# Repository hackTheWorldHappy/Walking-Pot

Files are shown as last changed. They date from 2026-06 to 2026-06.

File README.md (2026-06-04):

# WaPo Walking-Pot



A Pot on 6 Legs that walks towards the sun, to achive the best for it's flower.

While doing the project, I learned a lot of new Stuff. Before beginning this Project, I never touched a PCB modeling software. I did 3d Modelling a few time, but the best i got was a dice. So this Project is a step up. The Things I learned while doing this project, will help me a lot with other Projects.

## Key Facts
WaPo has 6 Legs with 3 Servo motors each to navigate the world.
To know where to go WaPo uses 8 light sensors/resistors to check the light levels around him.
WaPo will find the sensor with the most light, then it will rotate/move in the direction where the most light is registered. 

The PCB has a ESP Wroom chip and 2 PCA9685 LED/Servo Drivers, to be able to controll all 18 Servos at once.
The PCB fits into the bottom of the Pot.

## Why WaPo?
Besides that my plants are not living the best life (weak lightning), I want to explore Hexapods and the combination of all these servos to acctually move the robot.
Maybe that's the only way my plants can survive :)
My Idea was, to set WaPo on the Ground power it on and see where it goes to find the best Spot.

## How to Build your Own WaPo?
You can build your own WaPo by following these instructions: [INSTRUCTIONS.md](https://github.com/hackTheWorldHappy/Walking-Pot/blob/main/INSTRUCTIONS.md)

## Visuals
**Assembled 3D model**

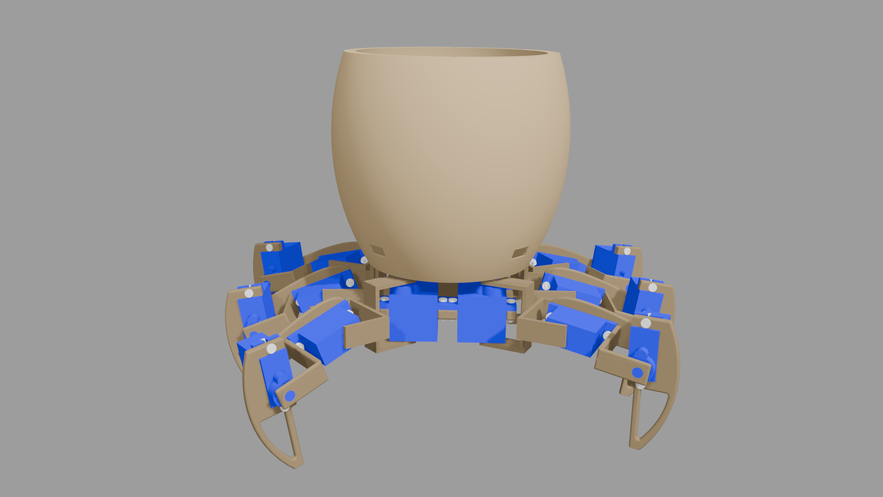
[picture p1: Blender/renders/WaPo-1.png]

<br>

**PCB 3D Model**

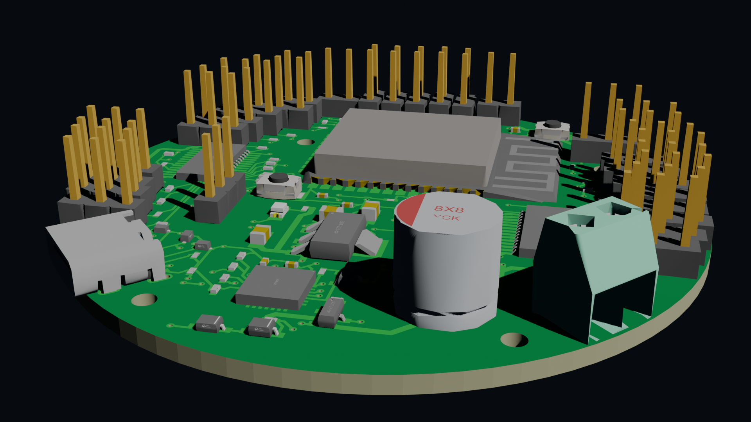
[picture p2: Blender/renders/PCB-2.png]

<br>

**PCB Schematic**

[WaPo-Schematic.pdf](https://github.com/hackTheWorldHappy/Walking-Pot/blob/main/SCH_WaPo-Schematic_2026-05-25.pdf)
<br>

**PCB Layout**

[PCB_wapo.pdf](https://github.com/hackTheWorldHappy/Walking-Pot/blob/main/PCB_PCB_wapo.pdf)

<br>

## Zine

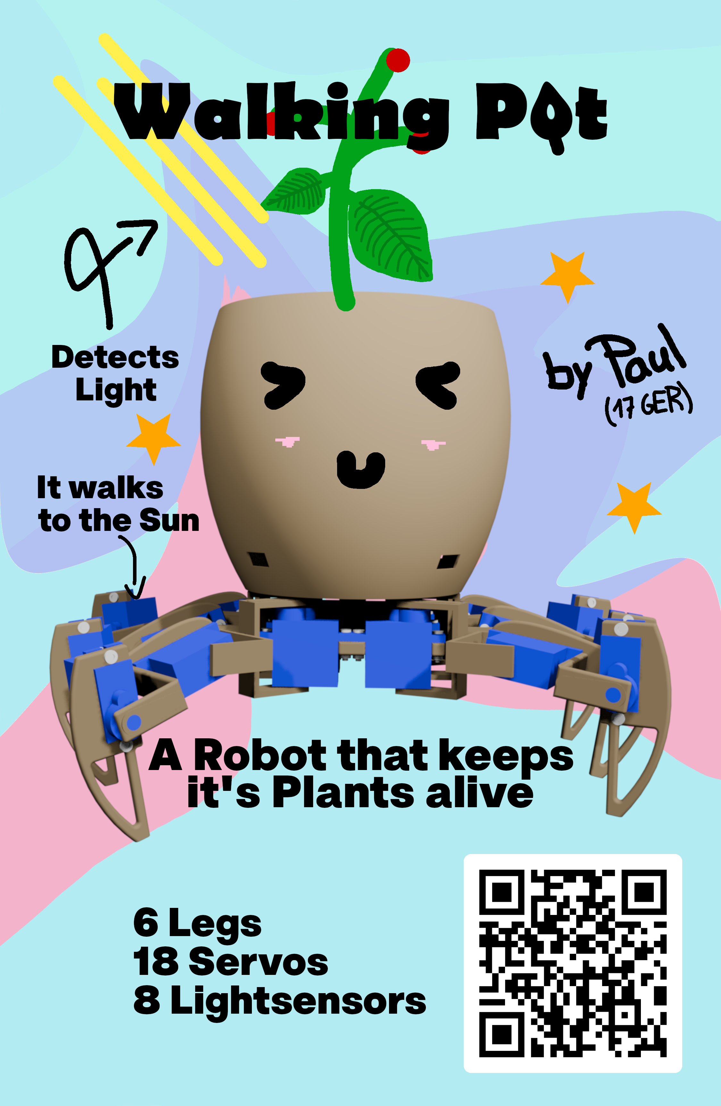
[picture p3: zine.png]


As a PDF: [Zine.pdf](https://github.com/hackTheWorldHappy/Walking-Pot/blob/main/zine.pdf)

---

## BOM
Name | Quantity | Price (for all) | Price in USD |Link
:------:|:-------:|:-------:|:-------:|:-------:
PCB (x5) | 1 (5) | ~22,73€ | ~26.44$ | [JLCPCB](https://jlcpcb.com) 
Servos sg90 | 18 | ~0,70€ | ~0.81$ | [AliExpress](https://de.aliexpress.com/item/1005007104370383.html)
Light Resistors | 8 | ~24,06€ | ~27.99$ | [AliExpress](https://de.aliexpress.com/item/32966282692.html)
M2 8mm Screws | 24 | ~0,79€ | ~0.92$ | [AliExpress](https://de.aliexpress.com/item/1005002247282771.html)
M2 10mm Screws | 12 | ~0,41€ | ~0.48$ | [AliExpress](https://de.aliexpress.com/item/1005002247282771.html)
M2 Nuts | 36 | ~1,13€ | ~1.31$ | [AliExpress](https://de.aliexpress.com/item/1005008314195033.html)  
Cables | 16 | ~2,11€ | ~2.45$ | [AliExpress](https://de.aliexpress.com/item/1005007046465880.html)
4.8V 3000mAh Battery | 1 | ~9,64€ | ~11.22$ | [AliExpress](https://de.aliexpress.com/item/1005006690430909.html)
PLA Filament Spool | 1 | ~15,43€ | ~17.95$ | [Amazon](https://www.amazon.com/dp/B0CD161SQR)
Total | | ~77,67€ | ~90.37$ | [BOM-all.csv](https://github.com/hackTheWorldHappy/Walking-Pot/blob/main/BOM-all.csv)
Actual Total* | | ~102,56€ | ~119.33$

*Actual Total: Cost including shipping and actual package size (Screws/Nuts come in 50PCS, Light resistors in 10)

View the PCB BOM as CSV: [BOM-PCB.csv](https://github.com/hackTheWorldHappy/Walking-Pot/blob/main/BOM-PCB.csv) <br>
View the BOM as CSV: [BOM.csv](https://github.com/hackTheWorldHappy/Walking-Pot/blob/main/BOM.csv)

---

## Firmware
### Libaries used in Firmware
https://github.com/adafruit/Adafruit-PWM-Servo-Driver-Library/tree/master

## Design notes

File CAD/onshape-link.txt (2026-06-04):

https://cad.onshape.com/documents/2002fa13ffcb19ab85ecd8a2/w/ecd96c98c772df3739a212b4/e/4dd37f64866b9c8d5d34c51d

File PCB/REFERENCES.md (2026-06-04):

# Refernces used for schematics/PCB creation:

### ESP32 WROOM Schematic
https://dl.espressif.com/dl/schematics/esp32_devkitc_v4_sch.pdf

### Adafruit PCA9685


_https://raw.githubusercontent.com/adafruit/Adafruit-16-Channel-PWM-Servo-Driver-PCB/refs/heads/master/Adafruit%20PCA9685.png_

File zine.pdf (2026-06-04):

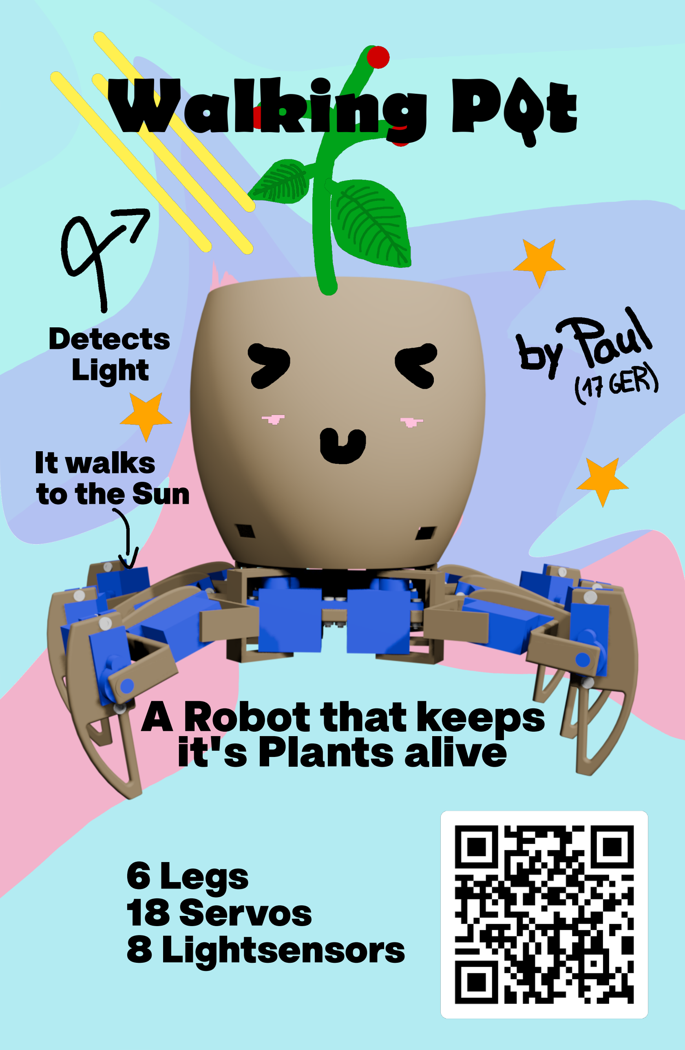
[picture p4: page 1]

### 6 Legs 18 Servos 8 Lightsensors

Light

Detects

to the Sun

It walks

A Robot that keeps it's Plants alive

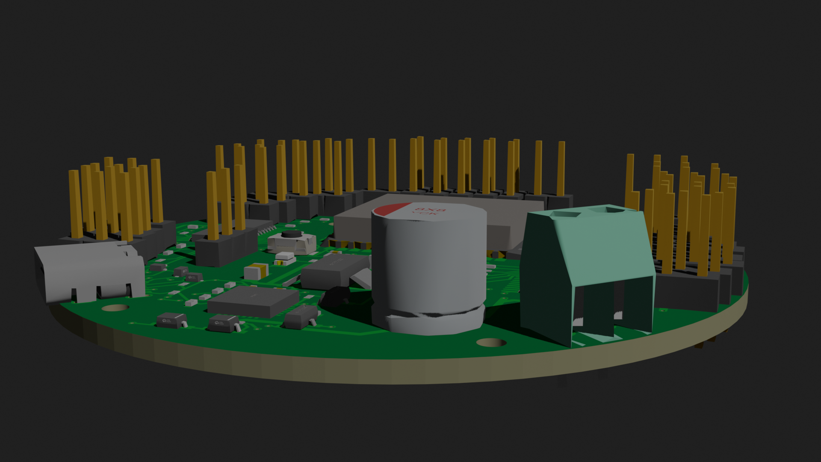
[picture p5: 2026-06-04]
Blender/renders/PCB-1.png

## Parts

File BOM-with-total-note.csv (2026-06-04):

No. | Quantity | Name | Comment | Designator | Footprint | Value | Manufacturer Part | Manufacturer | Supplier Part | Supplier | Price | Price * Quantity | per package Price | Link
1 | 3 | Capacitor | 22uF | C1,C3,C4 | C0805 | 22uF | CL21A226MPQNNNE | SAMSUNG(??) | C29277 | LCSC | 0,0038 € | 0,0114 € |  | https://www.lcsc.com/product-detail/C29277.html
2 | 5 | Capacitor | 100nF | C2,C5,C6,C7,C9 | C0402 | 100nF | CL05B104KO5NNNC | SAMSUNG(??) | C1525 | LCSC | 0,0003 € | 0,0015 € |  | https://www.lcsc.com/product-detail/C1525.html
3 | 1 | Capacitor | 10uF | C8 | C0402 | 10uF | CL05A106MP5NUNC | SAMSUNG(??) | C315248 | LCSC | 0,0015 € | 0,0015 € |  | https://www.lcsc.com/product-detail/C315248.html
4 | 2 | Capacitor | 10uF | C10,C11 | C0402 | 10uF | CL05A106MQ5NUNC | SAMSUNG(??) | C15525 | LCSC | 0,0011 € | 0,0022 € |  | https://www.lcsc.com/product-detail/C15525.html
5 | 1 | Capacitor | 1000uF | C12 | CAP-TH_BD8.0-P3.50-D0,6-FD | 1000uF | KM1A102MF115A00CV0 | HUAWEI(????) | C189254 | LCSC | 0,0091 € | 0,0091 € |  | https://www.lcsc.com/product-detail/C189254.html
6 | 1 | Diode | 1N4148WS | D1 | SOD-323_L1.8-W1.3-LS2.5-RD |  | 1N4148WS | CJ(????/??) | C2128 | LCSC | 0,0014 € | 0,0014 € |  | https://www.lcsc.com/product-detail/C2128.html
7 | 1 | Diode | BAT760-7 | D2 | SOD-323_L1.8-W1.3-LS2.5-RD |  | BAT760-7 | DIODES(??) | C124187 | LCSC | 0,0092 € | 0,0092 € |  | https://www.lcsc.com/product-detail/C124187.html
8 | 3 | TVS Diode | LESD5D5.0CT1G | D3,D4,D5 | SOD-523_L1.2-W0,8-LS1.6-BI |  | LESD5D5.0CT1G | UMW(?????) | C5199850 | LCSC | 0,0022 € | 0,0066 € |  | https://www.lcsc.com/product-detail/C5199850.html
9 | 8 | 2-Pin Male Header | PZ254V-11-02P | H1,H2,H3,H4,H5,H6,H7,H8 | HDR-TH_2P-P2.54-V-M |  | PZ254V-11-02P | XFCN(??) | C492401 | LCSC | 0,0024 € | 0,0192 € |  | https://www.lcsc.com/product-detail/C492401.html
10 | 18 | 3-Pin Male Header | 2.54-1*3P? | H9,H10,H11,H12,H13,H14,H15,H16,H17,H32,H33,H34,H35,H36,H37,H38,H39,H40 | HDR-TH_3P-P2.54-V-M-1 |  | 2.54-1*3P? | BOOMELE(????) | C49257 | LCSC | 0,0034 € | 0,0612 € |  | https://www.lcsc.com/product-detail/C49257.html
11 | 1 | LED Red | KT-0805R | LED1 | LED0805-R-RD |  | KT-0805R | KENTO | C2295 | LCSC | 0,0017 € | 0,0017 € |  | https://www.lcsc.com/product-detail/C2295.html
12 | 2 | Bipolar Transistor | SS8050-G(RANGE:200-350) | Q1,Q2 | SOT-23-3_L2.9-W1.3-P1.90-LS2.4-BR |  | SS8050-G(RANGE:200-350) | CJ(????/??) | C164885 | LCSC | 0,0023 € | 0,0046 € |  | https://www.lcsc.com/product-detail/C164885.html
13 | 1 | MOSFET | IRLML6401 | Q3 | SOT-23-3_L2.9-W1.3-P1.90-LS2.4-BR |  | IRLML6401 | KEXIN(??) | C382329 | LCSC | 0,0057 € | 0,0057 € |  | https://www.lcsc.com/product-detail/C382329.html
14 | 1 | Resistor | 2k? | R1 | R0402 | 2k? | 0402WGF2001TCE | UNI-ROYAL(??) | C4109 | LCSC | 0,0002 € | 0,0002 € |  | https://www.lcsc.com/product-detail/C4109.html
15 | 28 | Resistor | 10k? | R2,R3,R4,R5,R6,R7,R8,R9,R10,R18,R21,R22,R30,R31,R32,R33,R34,R35,R44,R58,R59,R60,R61,R65,R67,R68,R75,R76 | R0402 | 10k? | FRC0402F1002TS | FOJAN(??) | C2906861 | LCSC | 0,0001 € | 0,0028 € |  | https://www.lcsc.com/product-detail/C2906861.html
16 | 10 | Resistor | 0? | R11,R14,R17,R55,R56,R57,R64,R66,R77,R78 | R0402 | 0? | RC0402FR-070RL | YAGEO(??) | C106231 | LCSC | 0,0002 € | 0,0020 € |  | https://www.lcsc.com/product-detail/C106231.html
17 | 2 | Resistor | 5.1k? | R12,R13 | R0402 | 5.1k? | 0402WGF5101TCE | UNI-ROYAL(??) | C25905 | LCSC | 0,0002 € | 0,0004 € |  | https://www.lcsc.com/product-detail/C25905.html
18 | 18 | Resistor | 220? | R15,R16,R19,R20,R24,R25,R28,R29,R36,R54,R62,R63,R69,R70,R71,R72,R73,R74 | R0402 | 220? | 0402WGF2200TCE | UNI-ROYAL(??) | C25091 | LCSC | 0,0002 € | 0,0036 € |  | https://www.lcsc.com/product-detail/C25091.html
19 | 1 | Resistor | 22.1k? | R23 | R0402 | 22.1k? | 0402WGF2212TCE | UNI-ROYAL(??) | C43473 | LCSC | 0,0002 € | 0,0002 € |  | https://www.lcsc.com/product-detail/C43473.html
20 | 1 | Resistor | 47.5k? | R26 | R0402 | 47.5k? | 0402WGF4752TCE | UNI-ROYAL(??) | C25896 | LCSC | 0,0002 € | 0,0002 € |  | https://www.lcsc.com/product-detail/C25896.html
21 | 1 | Resistor | 1k? | R27 | R0402 | 1k? | 0402WGF1001TCE | UNI-ROYAL(??) | C11702 | LCSC | 0,0002 € | 0,0002 € |  | https://www.lcsc.com/product-detail/C11702.html
22 | 2 | Tactile Switch | TS-1088-AR02016 | SW1,SW2 | SW-SMD_L3.9-W3.0-P4.45 |  | TS-1088-AR02016 | XUNPU(??) | C720477 | LCSC | 0,0084 € | 0,0168 € |  | https://www.lcsc.com/product-detail/C720477.html
23 | 1 | ESP32 Microcontroller | 2.4GHz | U1 | WIFI-SMD_ESP32-WROOM-32E | 2.4GHz | ESP32-WROOM-32E-N16 | ESPRESSIF(??) | C701343 | LCSC | 0,6900 € | 0,6900 € |  | https://www.lcsc.com/product-detail/C701343.html
24 | 1 | Voltage Regulator 1A | AMS1117-3.3 | U2 | SOT-223-4_L6.5-W3.5-P2.30-LS7.0-BR |  | AMS1117-3.3 | UMW(?????) | C347222 | LCSC | 0,0063 € | 0,0063 € |  | https://www.lcsc.com/product-detail/C347222.html
25 | 1 | USB-to-UART Bridge | CP2102N-A02-GQFN28R | U3 | QFN-28_L5.0-W5.0-P0,50-TL-EP3.3 |  | CP2102N-A02-GQFN28R | SKYWORKS/SILICON LABS(??) | C964632 | LCSC | 0,2422 € | 0,2422 € |  | https://www.lcsc.com/product-detail/C964632.html
26 | 2 | PWM Controller | PCA9685PW,118 | U4,U5 | TSSOP-28_L9.7-W4.4-P0,65-LS6.4-TL | - | PCA9685PW,118 | NXP(???) | C2678753 | LCSC | 0,4910 € | 0,9820 € |  | https://www.lcsc.com/product-detail/C2678753.html
27 | 1 | 2 Wire to Board | DB301V-3.5-2P-GN-S | U6 | CONN-TH_DB301V-3.5-2P-GN |  | DB301V-3.5-2P-GN-S | DORABO(????) | C695629 | LCSC | 0,0139 € | 0,0139 € |  | https://www.lcsc.com/product-detail/C695629.html
28 | 1 | USB-C Connector | TYPE-C16PIN | USB1 | USB-C-SMD_TYPE-C16PIN |  | TYPE-C16PIN | SHOU HAN(??) | C393939 | LCSC | 0,0106 € | 0,0106 € |  | https://www.lcsc.com/product-detail/C393939.html
29 | 5 | PCB minus components |  |  |  |  |  |  |  |  |  | 22,7300 € |  | https://jlcpcb.com
30 | 18 | Servo sg90 | Buy x6 3PCS |  |  |  |  |  |  |  | 1,3367 € | 24,0600 € | 4,0100 € | https://de.aliexpress.com/item/1005007104370383.html
31 | 8 | Light Resistors | Available in 10PCS |  |  |  |  |  |  |  | 0,0870 € | 0,6960 € | 0,8700 € | https://de.aliexpress.com/item/32966282692.html
32 | 24 | M2 8mm Screw | Only Available in 50PCS |  |  |  |  |  |  |  | 0,0330 € | 0,7920 € | 1,65 € | https://de.aliexpress.com/item/1005002247282771.html
33 | 12 | M2 10mm Screw | Only Available in 50PCS |  |  |  |  |  |  |  | 0,0344 € | 0,4128 € | 1,72 € | https://de.aliexpress.com/item/1005002247282771.html
34 | 36 | M2 Nut | Only Available in 50PCS |  |  |  |  |  |  |  | 0,0314 | 1,1304 € | 1,57 € | https://de.aliexpress.com/item/1005008314195033.html
35 | 16 | Cables | For the Light Resistors |  |  |  |  |  |  |  | 0,13 € | 2,1120 € | 2,64 € | https://de.aliexpress.com/item/1005007046465880.html
36 | 1 | 4.8V 3000mAh Battery |  |  |  |  |  |  |  |  | 9,64 € | 9,6400 € | 9,64 € | https://de.aliexpress.com/item/1005006690430909.html
37 | 1 | PLA Filament Spool | Choose your Color |  |  |  |  |  |  |  | 15,43 € | 15,4300 € | 15,43 € | https://www.amazon.com/dp/B0CD161SQR
 |  |  | JLCPCB Components | JLCPCB PCB (for 5) | AliExpress | Amazon |  | SubTotal | Total | Total (aliexpress new customer) |  | 77,0032 €
 |  |  | 2,1067 € | 22,7300 € | 42,1500 € | 15,4300 € |  | 80,3100 € | 105,2000 € | 95,1100 €
 |  | shipping |  | 1,2900 € | 13,6600 € | 9,94 € |  | 24,8900 €
 |  | new customer (total) |  |  | 45,7200 € |  |  | 45,72 € | 45,72 €
 | Total | 105,2000 € |  | Total (aliexpress new customer) | 95,1100 €

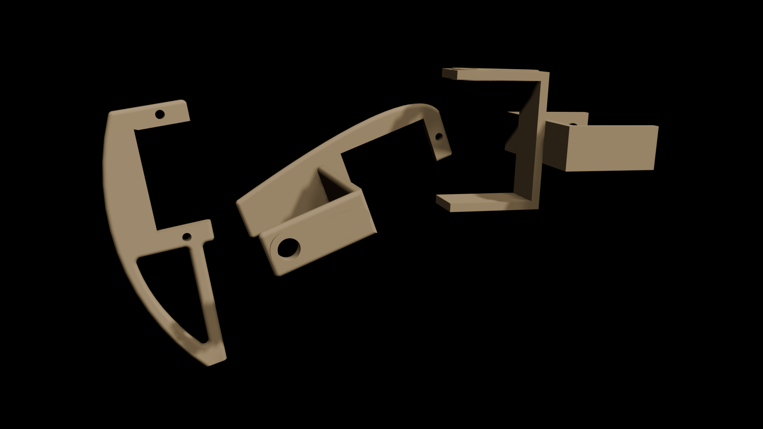
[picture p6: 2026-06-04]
Blender/renders/leg-parts.png

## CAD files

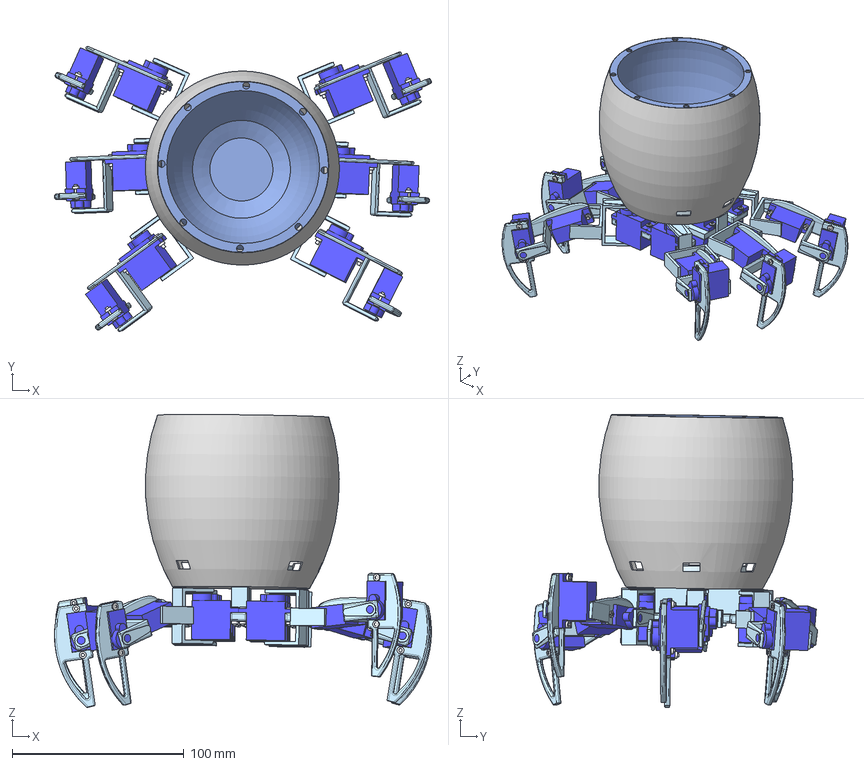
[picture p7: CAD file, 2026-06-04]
CAD/WaPo_Assembly_step.step
219.7 x 166.2 x 170.8 mm

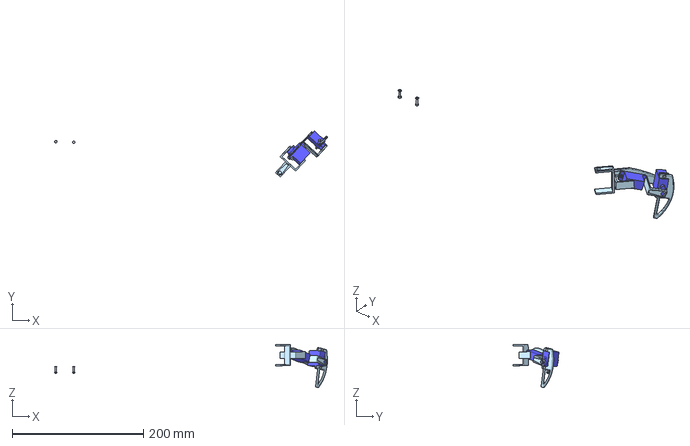
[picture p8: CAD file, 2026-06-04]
CAD/Leg 2.step
416.0 x 70.3 x 65.9 mm

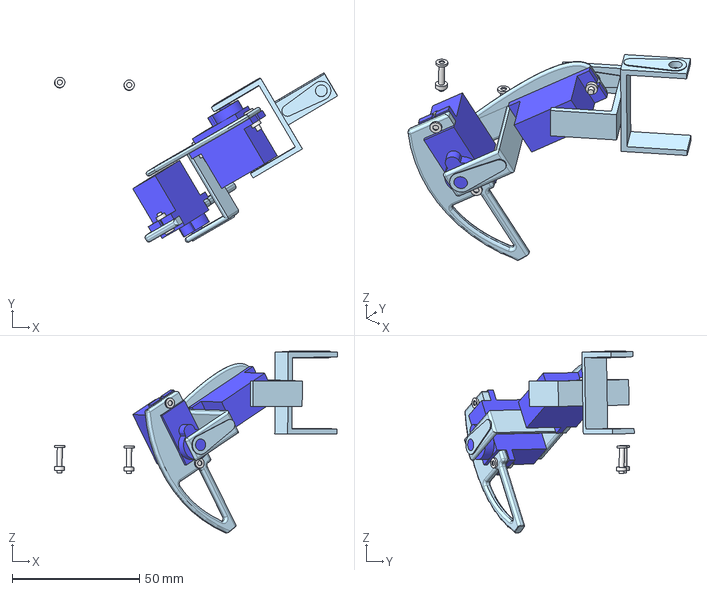
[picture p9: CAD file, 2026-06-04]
CAD/Leg 1.step
111.2 x 66.6 x 71.4 mm

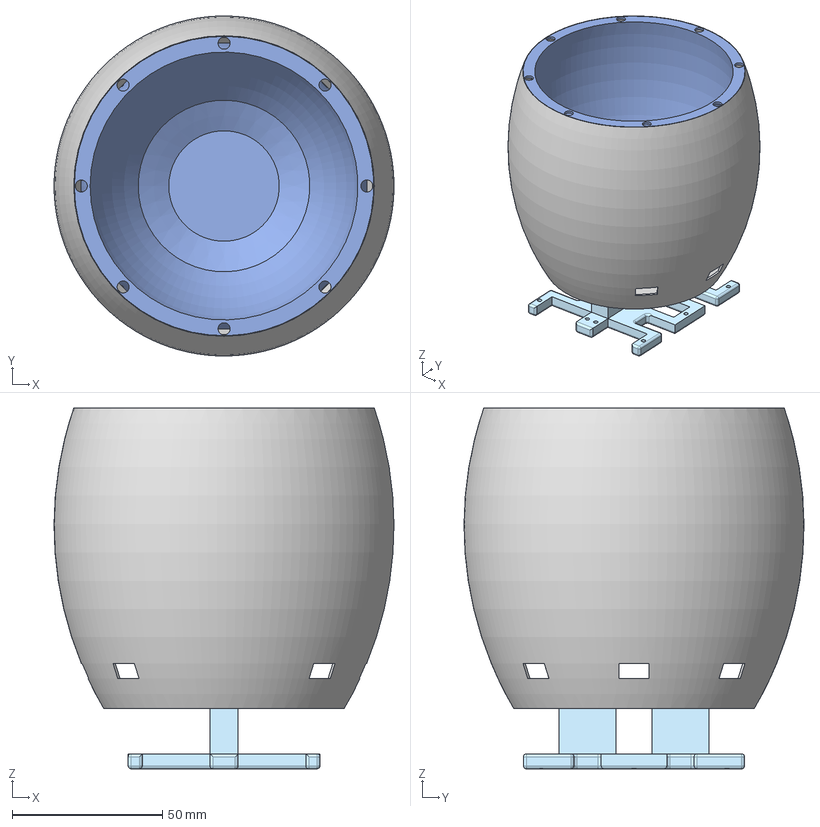
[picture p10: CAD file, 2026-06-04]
CAD/Pot.step
113.1 x 113.1 x 120.0 mm

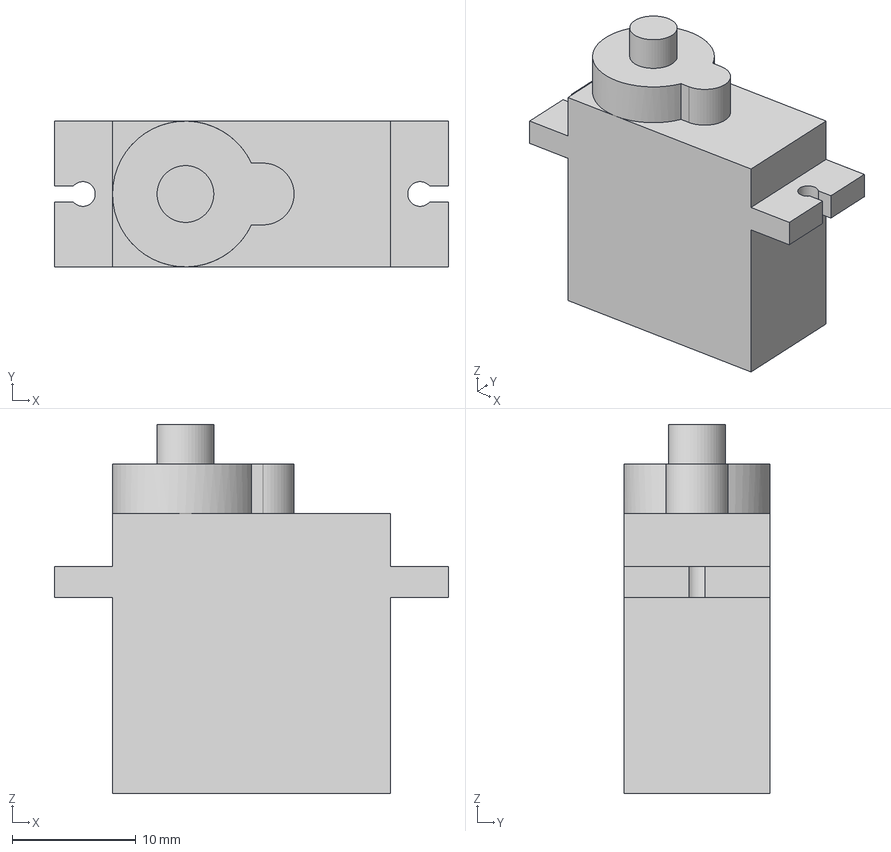
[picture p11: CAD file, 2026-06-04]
CAD/servo reference.step
31.9 x 11.8 x 29.9 mm

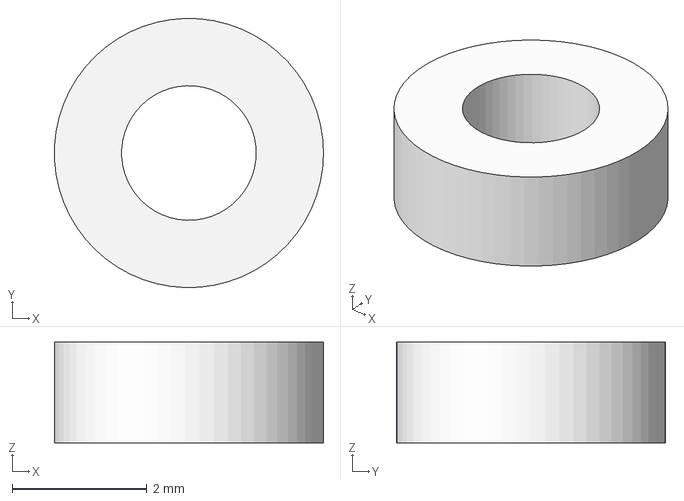
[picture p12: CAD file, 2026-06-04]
CAD/Screw and Nut 10mm/Screw and Nut 10mm - Part 1.step
4.00 x 4.00 x 1.50 mm

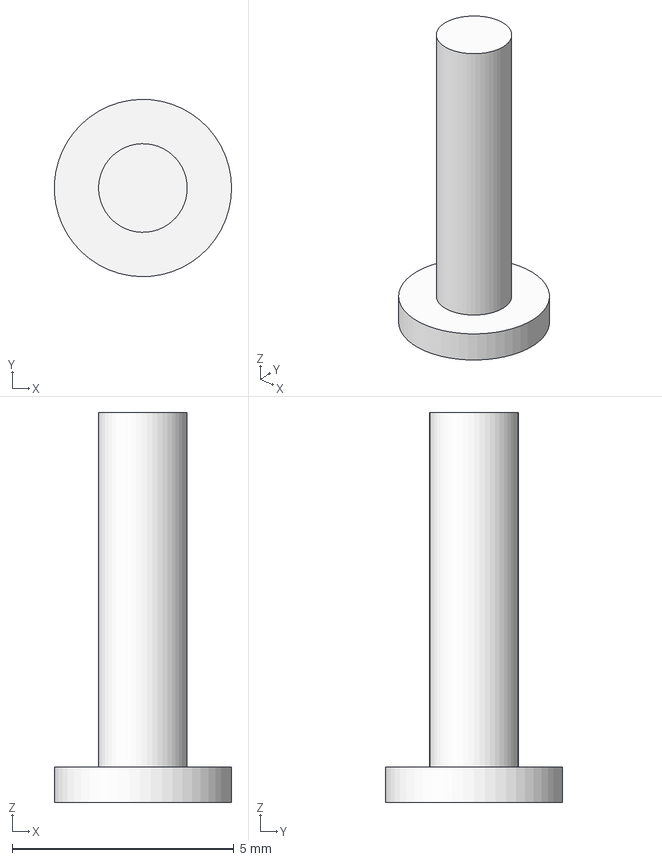
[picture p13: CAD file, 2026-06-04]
CAD/Screw and Nut 8mm/Screw and Nut 8mm - Part 1.step
4.00 x 4.00 x 8.80 mm

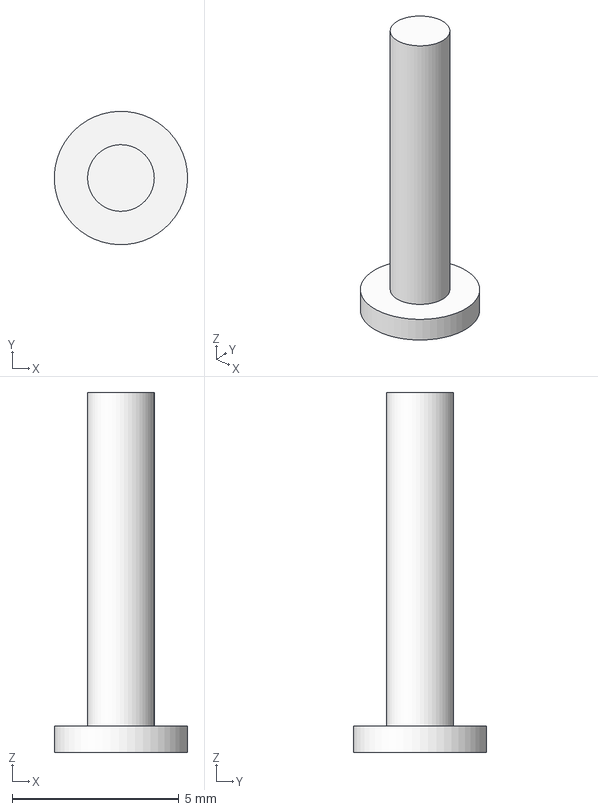
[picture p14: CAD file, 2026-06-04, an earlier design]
CAD/Screw and Nut 10mm/Screw and Nut 10mm - Part 1 (1).step
4.00 x 4.00 x 10.8 mm

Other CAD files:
CAD/Screw and Nut 8mm/Screw and Nut 8mm - Part 1 (1).step
Blender/PCB.blend

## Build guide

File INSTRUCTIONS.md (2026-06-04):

# WaPo Instructions
These are the instructions for building the WaPo.

## Ordering the PCB

First, upload the gerber files

Recommended Settings:

    Layers: 4
    Dimensions: 60mm x 60mm
    PCB Thickness: 1.6mm

## Software
For the start flush the PCB with the [buildDebug.ino](https://github.com/hackTheWorldHappy/Walking-Pot/blob/main/firmware/buildDebug.ino) Script. It sets the Servos in the right postition, so when you put the Servo head on top, it will be right.
After Building WaPo, you can put the [script.ino](https://github.com/hackTheWorldHappy/Walking-Pot/blob/main/firmware/script.ino) on the PCB/Microcontroller and it should walk to the Sun on battery connection.

## Assembling

### Base Plate
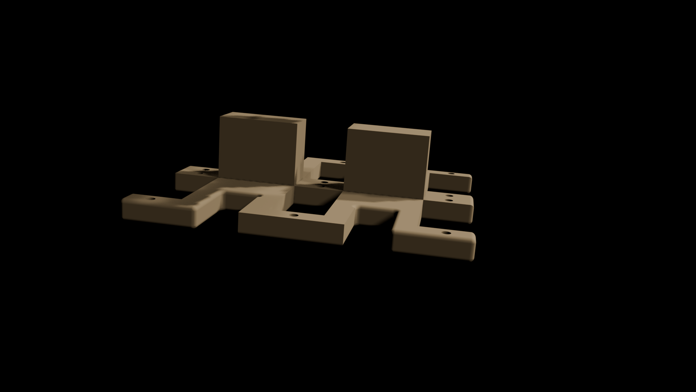
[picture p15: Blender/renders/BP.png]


Add 6 Servos like this and assembly them with 12 M2 10mm Screw and 12 M2 Nuts 
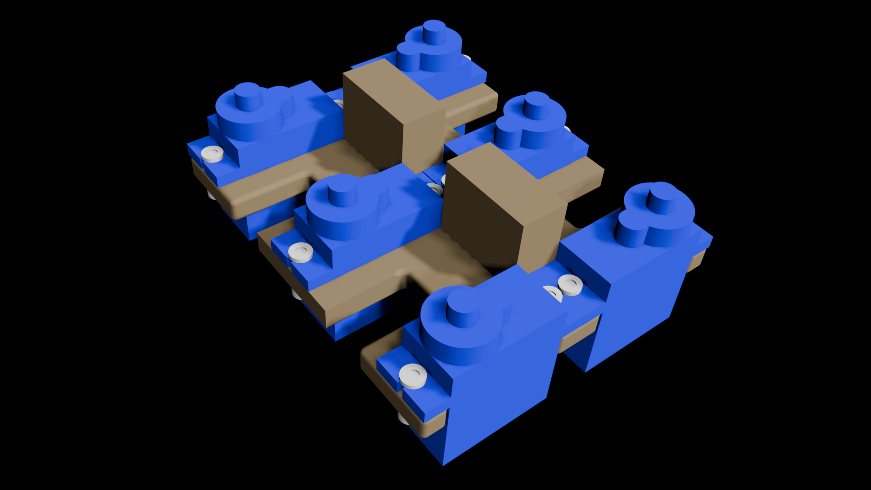
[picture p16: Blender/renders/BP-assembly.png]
 
<br>

### Legs

There are 6 Legs.
Every Leg has 3 parts, that need to be printed and assembled:
The 3 Leg Parts 3d Render

Leg Assembly with 2 Servos and 4  M2 8mm Screw and 4 M2 Nuts

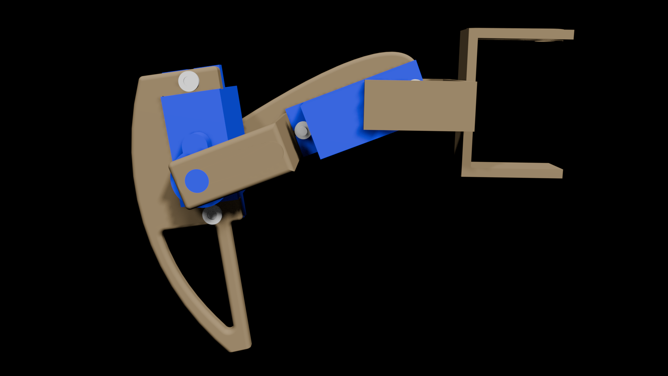
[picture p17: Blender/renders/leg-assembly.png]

<br>

### Pot

The Pot is two Parts where the PCB fits inbetween

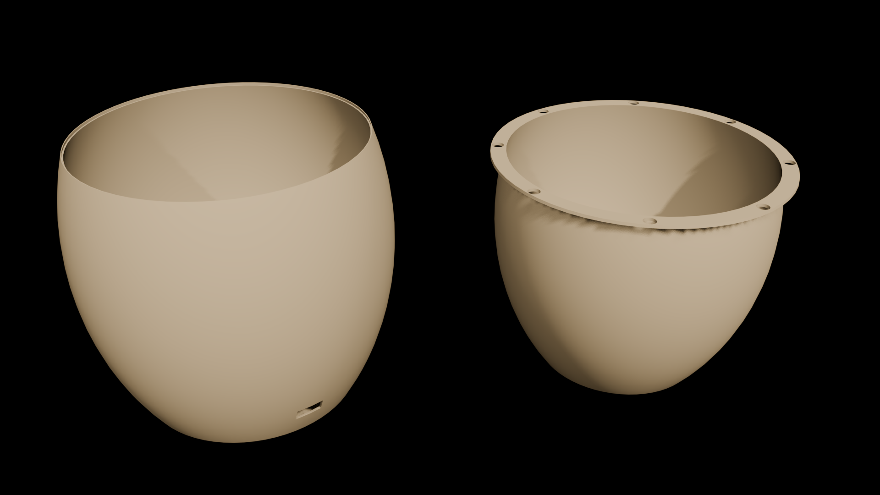
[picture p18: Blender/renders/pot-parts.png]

<br>

Put the PCB through the pins from the outer pot shell, then add the Servo cables and the Light sensor Cables.
The Servo Cables go through the holes of the outer shell.
Solder/Put the Lightresistors to the Cables peaking out of the Holes from the inner Shell.

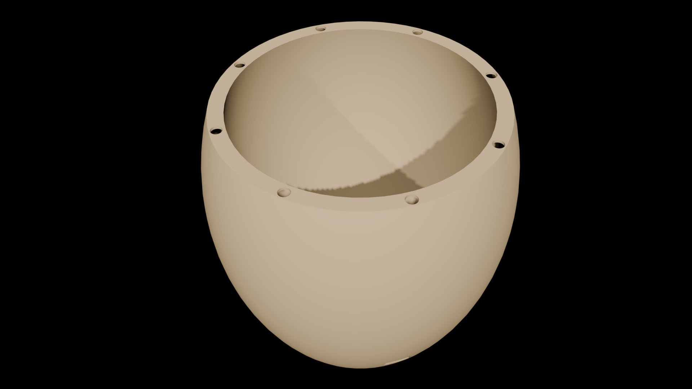
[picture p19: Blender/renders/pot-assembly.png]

<br>

The Lightresistor Placement should look like this:

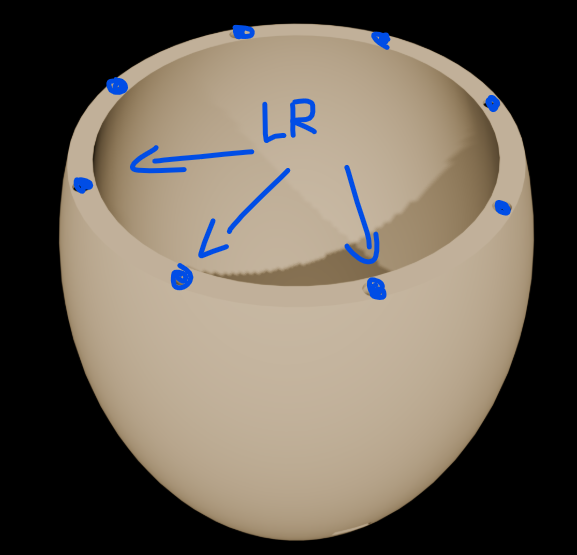
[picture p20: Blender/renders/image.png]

<br>

### Put it together

Put the Leg on the Servo and then the servo head on top

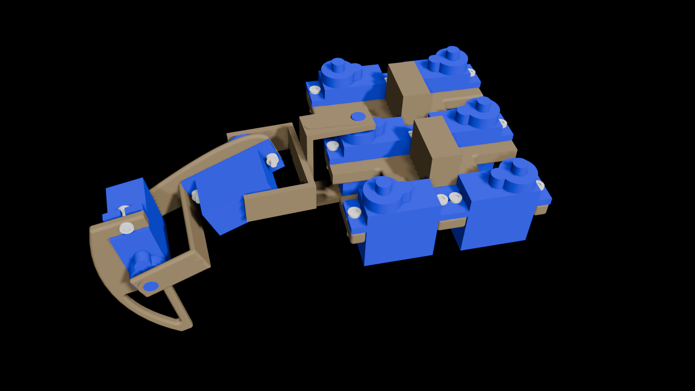
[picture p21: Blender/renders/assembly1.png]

<br>

The put the pins from the outer shell into the holes from the Base Plate (you can glue it if you want).
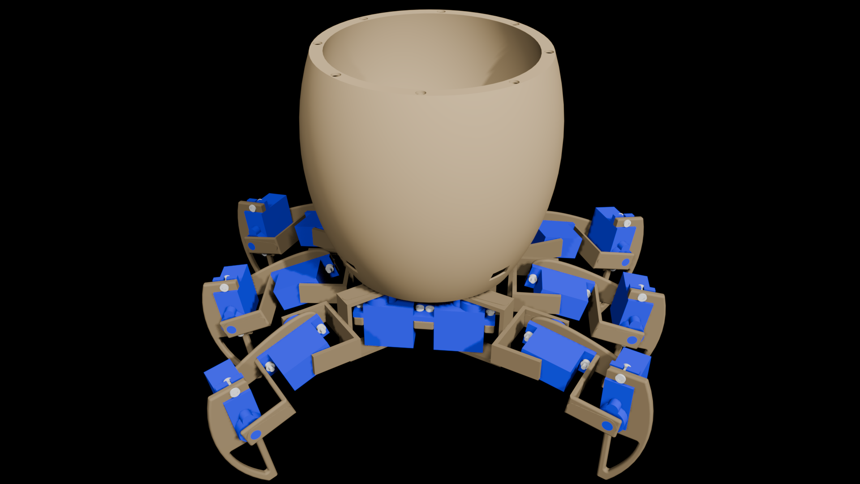
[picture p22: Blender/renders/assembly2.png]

<br>

Last, add the battery between the outer shell and the inner shell. <br>
Add Dirt in the Pot and a beautiful Flower or Plant. <br>
Now WaPo is finished :)

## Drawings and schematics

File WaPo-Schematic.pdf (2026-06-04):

# Power Supply

# ESP32 Module

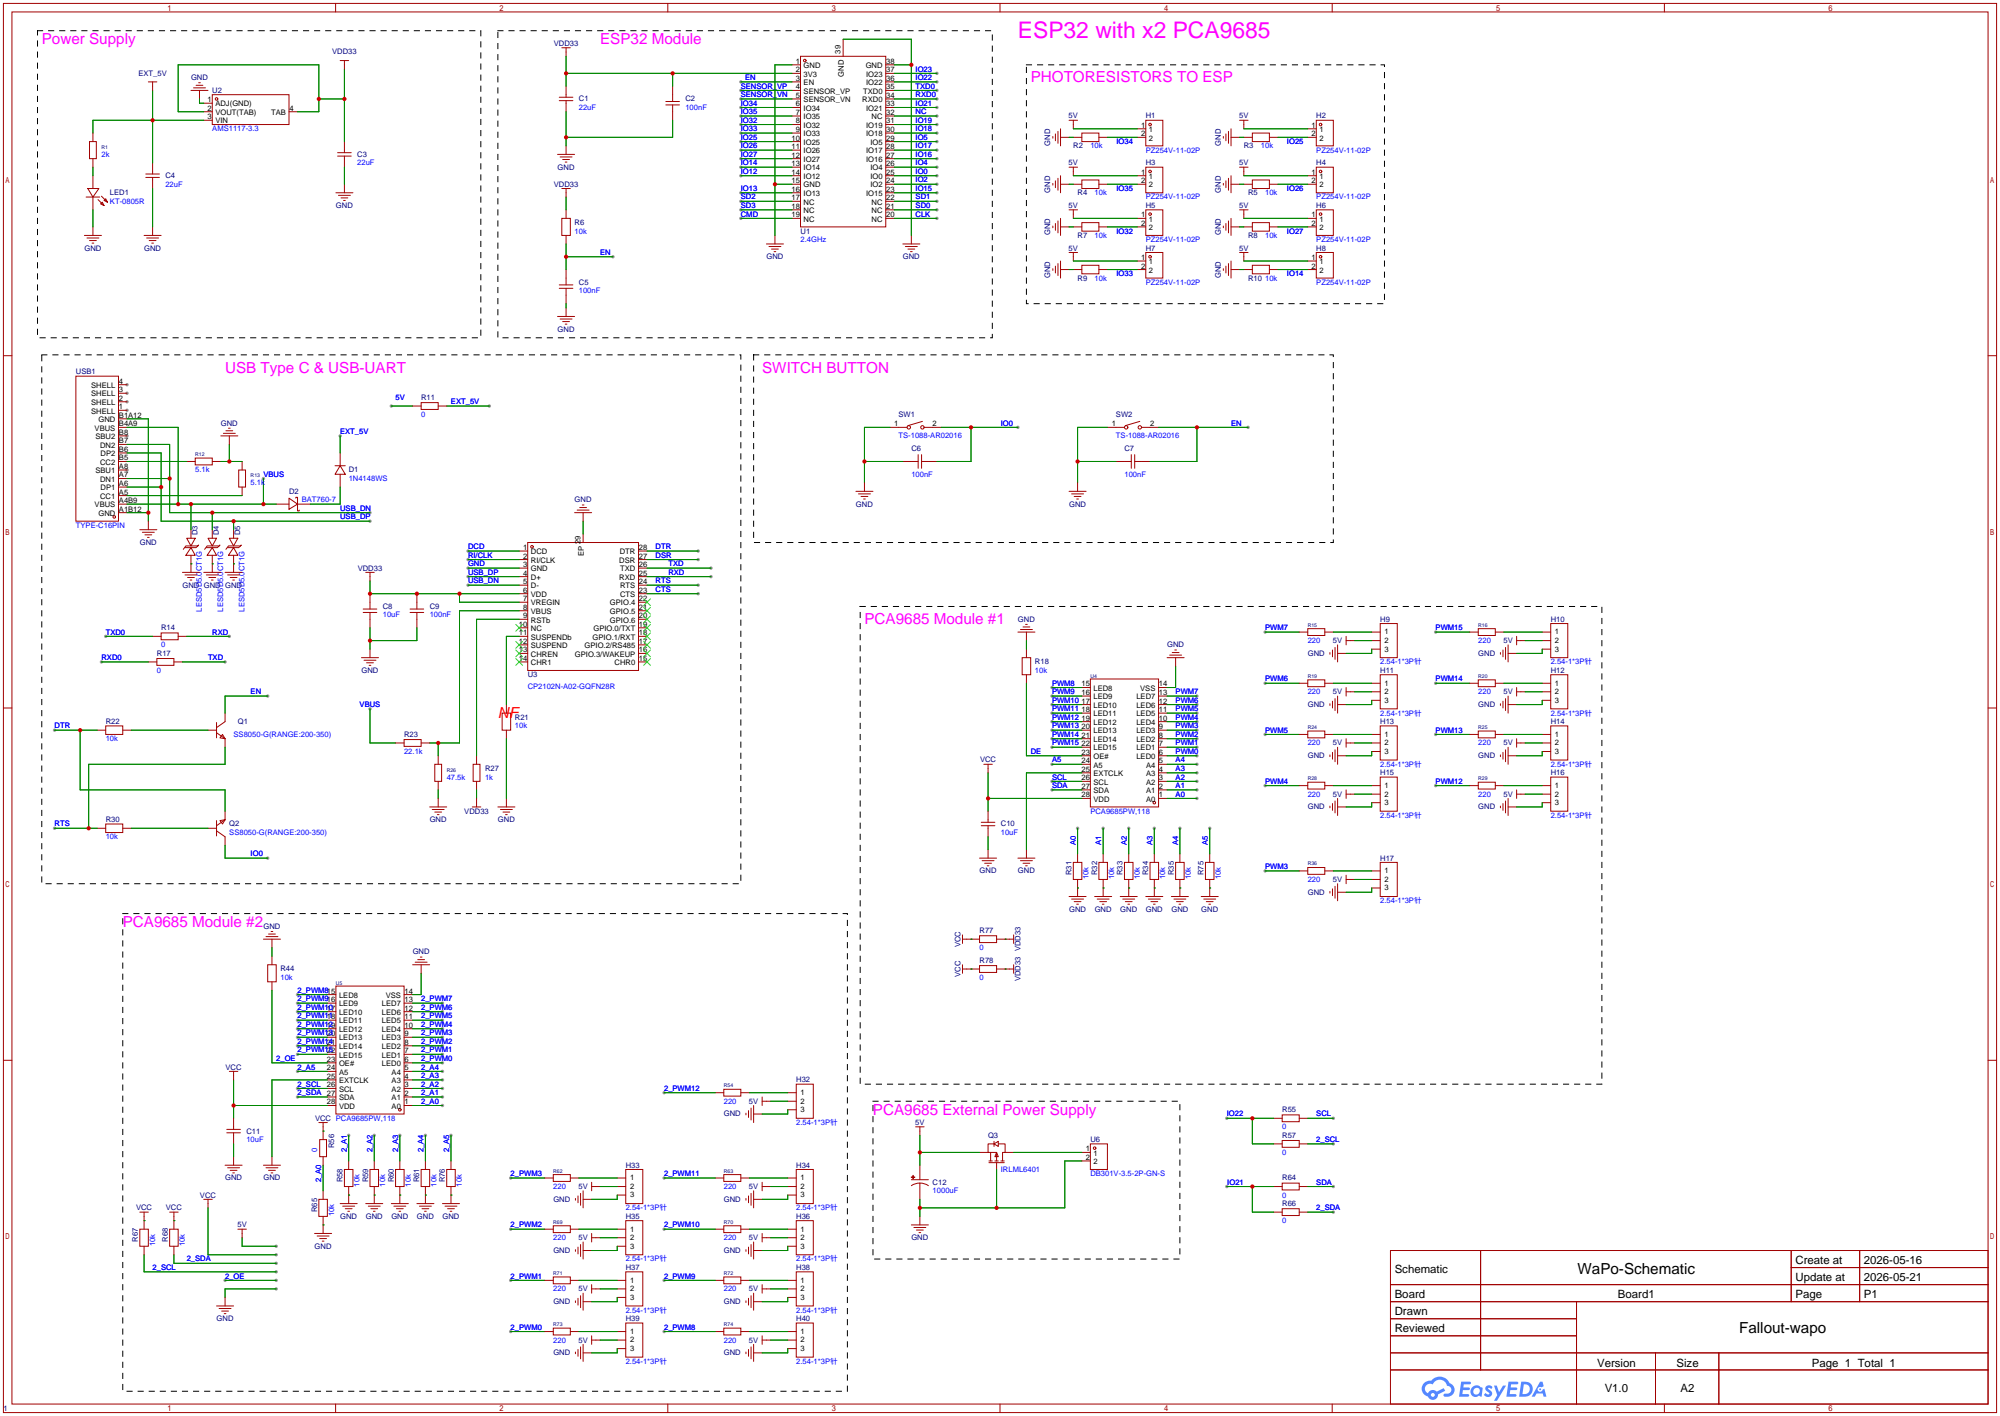
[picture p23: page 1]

USB Type C & USB-UART
GND A1B12 VBUS A4B9 CC1 A5 DP1 A6 DN1 A7 SBU1 A8 CC2 B5 DP2 B6 DN2 B7 SBU2 B8 VBUS B4A9 GND B1A12 SHELL 1

GND GND

Schematic | WaPo-Schematic | Create at | 2026-05-16

Update at | 2026-05-21

Board | Board1 | Page | P1
Drawn | | Fallout-wapo
Reviewed

Version | Size | Page 1 Total 1
V1.0 | A2

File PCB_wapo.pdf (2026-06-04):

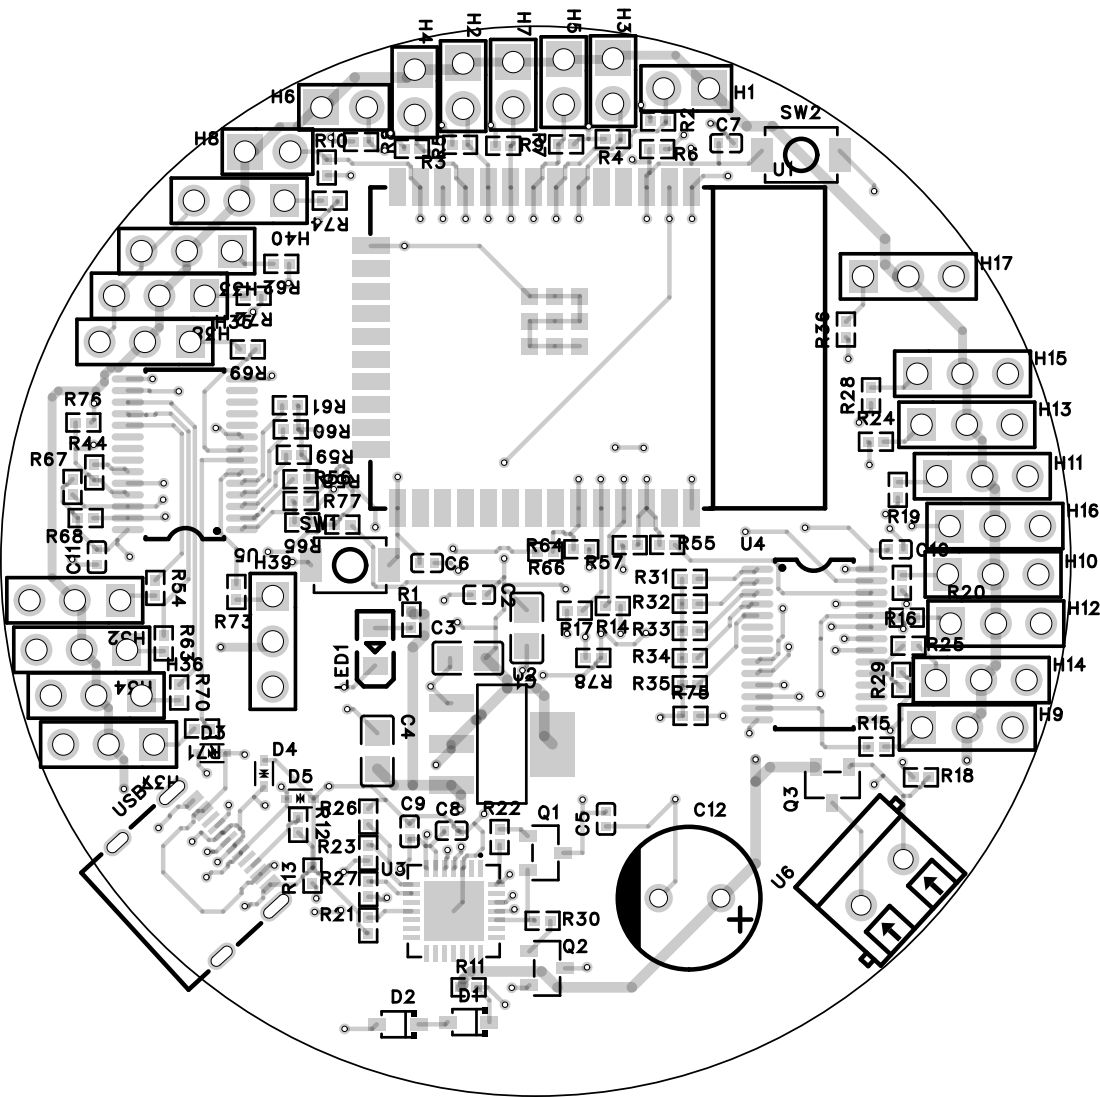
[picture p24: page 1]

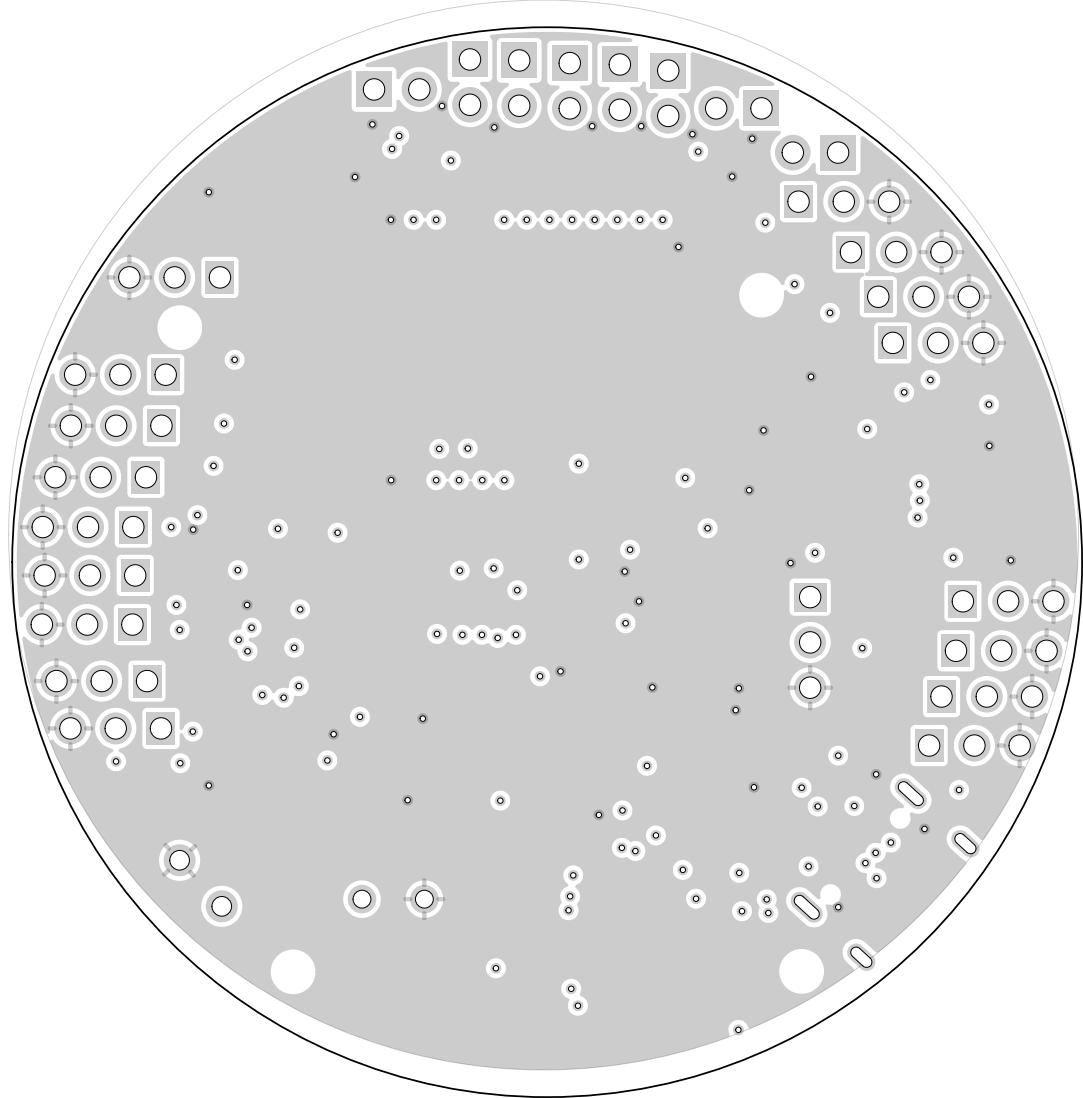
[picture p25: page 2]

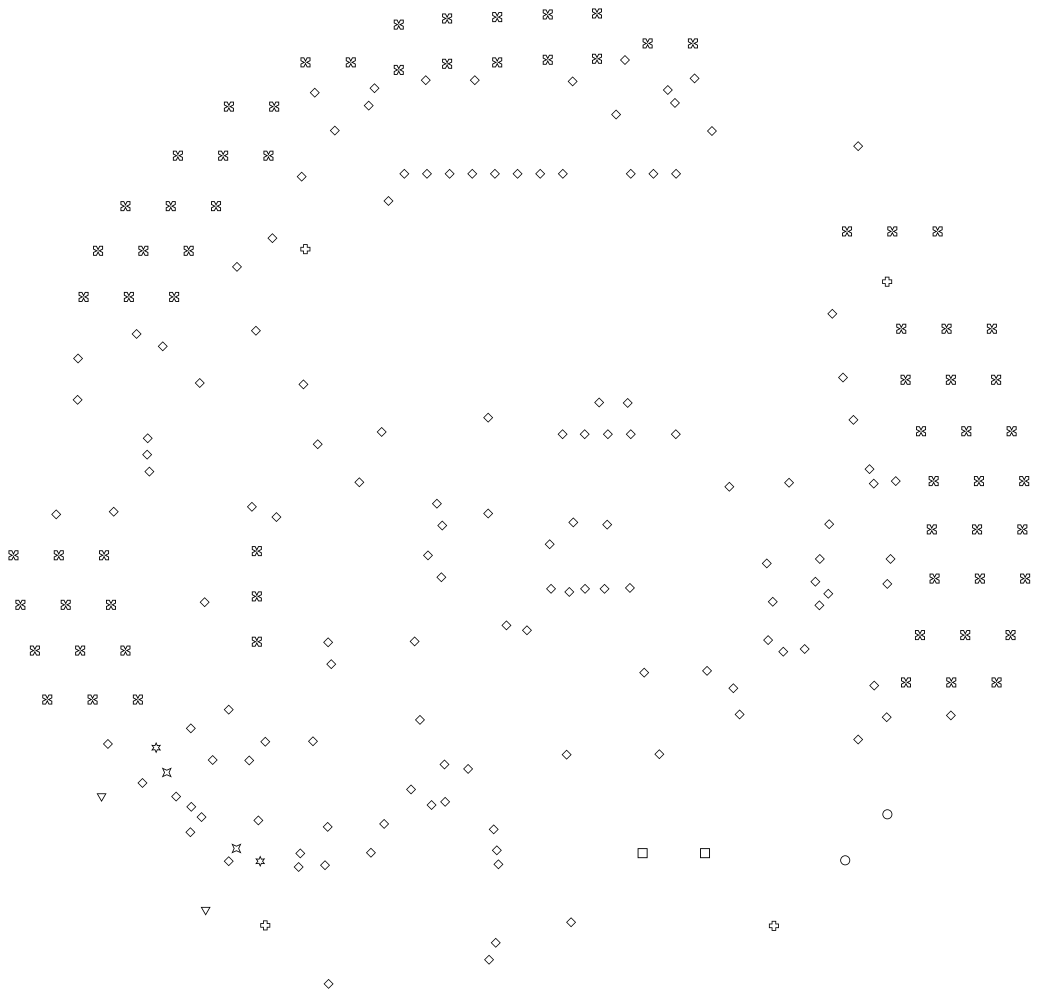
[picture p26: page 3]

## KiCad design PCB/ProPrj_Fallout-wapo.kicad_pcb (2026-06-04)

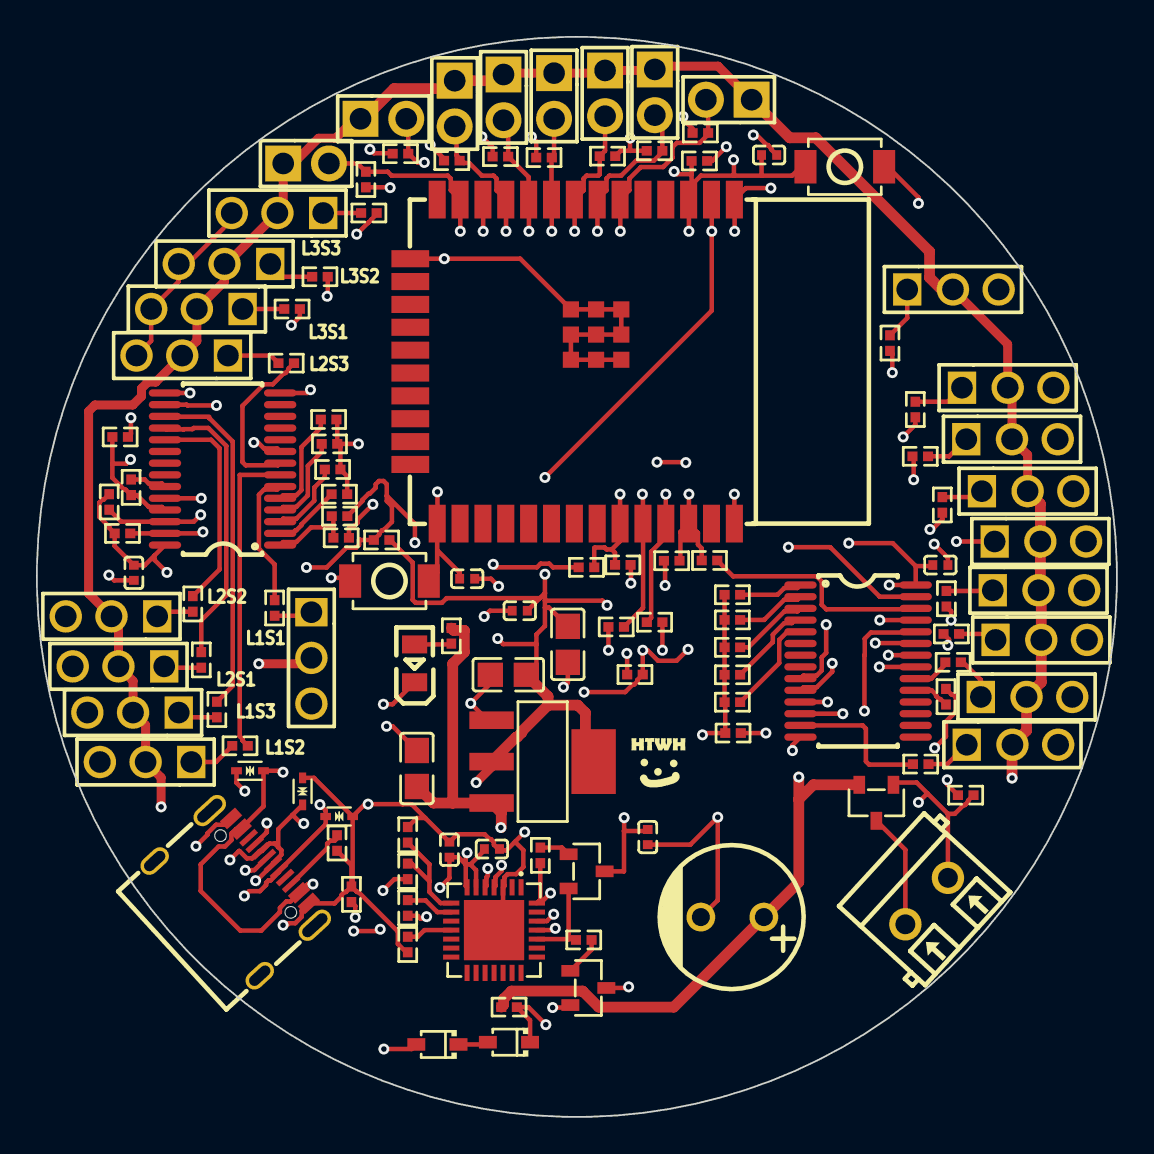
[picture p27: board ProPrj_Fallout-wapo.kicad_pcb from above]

Board: 4 copper layers, 60.0 x 60.0 mm, 118 parts (0 on the bottom side), 90 nets.

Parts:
C1, C3, C4: C0805
C2, C5, C6, C7, C8, C9, C10, C11: C0402
C12: CAP-TH_BD8.0-P3.50-D0.6-FD
D1, D2: SOD-323_L1.8-W1.3-LS2.5-RD
D3, D4, D5: SOD-523_L1.2-W0.8-LS1.6-BI
H1, H2, H3, H4, H5, H6, H7, H8: HDR-TH_2P-P2.54-V-M
H9, H10, H11, H12, H13, H14, H15, H16, H17, H32, H33, H34, H35, H36, H37, H38, H39, H40: HDR-TH_3P-P2.54-V-M-1
LED1: LED0805-R-RD
Q1, Q2, Q3: SOT-23-3_L2.9-W1.3-P1.90-LS2.4-BR
R1, R2, R3, R4, R5, R6, R7, R8, R9, R10, R11, R12, R13, R14, R15, R16, R17, R18, R19, R20, R21, R22, R23, R24, R25, R26, R27, R28, R29, R30, R31, R32, R33, R34, R35, R36, R44, R54, R55, R56, R57, R58, R59, R60, R61, R62, R63, R64, R65, R66, R67, R68, R69, R70, R71, R72, R73, R74, R75, R76, R77, R78: R0402
SW1, SW2: SW-SMD_L3.9-W3.0-P4.45
U1: WIFI-SMD_ESP32-WROOM-32E
U2: SOT-223-4_L6.5-W3.5-P2.30-LS7.0-BR
U3: QFN-28_L5.0-W5.0-P0.50-TL-EP3.3
U4, U5: TSSOP-28_L9.7-W4.4-P0.65-LS6.4-TL
U6: CONN-TH_DB301V-3.5-2P-GN
USB1: USB-C-SMD_TYPE-C16PIN

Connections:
2_A0: R56.1, R65.2, U5.1
2_A1: R58.2, U5.2
2_A2: R59.2, U5.3
2_A3: R60.2, U5.4
2_A4: R61.2, U5.5
2_A5: R76.2, U5.24
2_OE: R44.2, U5.23
2_PWM0: R73.1, U5.6
2_PWM1: R71.1, U5.7
2_PWM2: R69.1, U5.8
2_PWM3: R62.1, U5.9
2_PWM8: R74.1, U5.15
2_PWM9: R72.1, U5.16
2_PWM10: R70.1, U5.17
2_PWM11: R63.1, U5.18
2_PWM12: R54.1, U5.19
2_SCL: R57.2, R67.1, U5.26
2_SDA: R66.2, R68.1, U5.27
5V: C12.1, H1.1, H2.1, H3.1, H4.1, H5.1, H6.1, H7.1, H8.1, H9.2, H10.2, H11.2, H12.2, H13.2, H14.2, H15.2, H16.2, H17.2, H32.2, H33.2, H34.2, H35.2, H36.2, H37.2, H38.2, H39.2, H40.2, Q3.2, R11.1
$1N6269: R23.2, R26.2, U3.8
$1N6573: R27.2, U3.9
$1N6578: R21.2, U3.11
$1N6667: Q1.1, R22.2
$1N6671: Q2.1, R30.2
$1N6829: LED1.1, R1.1
$1N7006: R12.1, USB1.B5
$1N7052: R13.1, USB1.A5
$1N8815: Q3.3, U6.1
$1N9207: H9.1, R15.2
$1N9376: H11.1, R19.2
$1N9498: H13.1, R24.2
$1N9620: H15.1, R28.2
$1N9742: H10.1, R16.2
$1N9864: H12.1, R20.2
$1N9986: H14.1, R25.2
$1N10108: H16.1, R29.2
$1N11068: H17.1, R36.2
$1N16727: H40.1, R74.2
$1N16737: H38.1, R72.2
$1N16739: H36.1, R70.2
$1N16752: H34.1, R63.2
$1N16762: H39.1, R73.2
$1N16775: H37.1, R71.2
$1N16785: H35.1, R69.2
$1N16789: H33.1, R62.2
$1N16810: H32.1, R54.2
$1N22039: D1.2, D2.1
A0: R31.2, U4.1
A1: R32.2, U4.2
A2: R33.2, U4.3
A3: R34.2, U4.4
A4: R35.2, U4.5
A5: R75.2, U4.24
DE: R18.2, U4.23
DTR: Q2.2, R22.1, U3.28
EN: C5.2, C7.2, Q1.3, R6.1, SW2.2, U1.3
EXT_5V: C4.2, D1.1, R1.2, R11.2, U2.3
GND: C1.1, C2.1, C3.1, C4.1, C5.1, C6.1, C7.1, C8.1, C9.1, C10.1, C11.1, C12.2, D3.1, D4.1, D5.1, H9.3, H10.3, H11.3, H12.3, H13.3, H14.3, H15.3, H16.3, H17.3, H32.3, H33.3, H34.3, H35.3, H36.3, H37.3, H38.3, H39.3, H40.3, LED1.2, Q3.1, R2.2, R3.2, R4.2, R5.2, R7.2, R8.2, R9.2, R10.2, R12.2, R13.2, R18.1, R21.1, R26.1, R31.1, R32.1, R33.1, R34.1, R35.1, R44.1, R58.1, R59.1, R60.1, R61.1, R65.1, R75.1, R76.1, SW1.1, SW2.1, U1.1, U1.15, U1.38, U1.39, U2.1, U3.3, U3.29, U4.14, U4.25, U5.14, U5.25, U6.2, USB1.A1B12, USB1.B1A12
IO0: C6.2, Q2.3, SW1.2, U1.25
IO14: H8.2, R10.1, U1.13
IO21: R64.1, R66.1, U1.33
IO22: R55.1, R57.1, U1.36
IO25: H2.2, R3.1, U1.10
IO26: H4.2, R5.1, U1.11
IO27: H6.2, R8.1, U1.12
IO32: H5.2, R7.1, U1.8
IO33: H7.2, R9.1, U1.9
IO34: H1.2, R2.1, U1.6
IO35: H3.2, R4.1, U1.7
PWM3: R36.1, U4.9
PWM4: R28.1, U4.10
PWM5: R24.1, U4.11
PWM6: R19.1, U4.12
PWM7: R15.1, U4.13
PWM12: R29.1, U4.19
PWM13: R25.1, U4.20
PWM14: R20.1, U4.21
PWM15: R16.1, U4.22
RTS: Q1.2, R30.1, U3.24
RXD: R14.2, U3.25
RXD0: R17.1, U1.34
SCL: R55.2, U4.26
SDA: R64.2, U4.27
TXD: R17.2, U3.26
TXD0: R14.1, U1.35
USB_DN: D4.2, U3.5, USB1.A7, USB1.B7
USB_DP: D5.2, U3.4, USB1.A6, USB1.B6
VBUS: D2.2, D3.2, R23.1, USB1.A4B9, USB1.B4A9
VCC: C10.2, C11.2, R56.2, R67.2, R68.2, R77.1, R78.1, U4.28, U5.28
VDD33: C1.2, C2.2, C3.2, C8.2, C9.2, R6.2, R27.1, R77.2, R78.2, U1.2, U2.2, U2.4, U3.6, U3.7

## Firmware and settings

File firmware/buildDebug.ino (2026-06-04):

#include <Wire.h>
#include <Adafruit_PWMServoDriver.h>

Adafruit_PWMServoDriver pwmRight = Adafruit_PWMServoDriver(0x40);
Adafruit_PWMServoDriver pwmLeft = Adafruit_PWMServoDriver(0x41);


#define SERVOMIN 150   // This is the 'minimum' pulse length count (out of 4096)
#define SERVOMAX 600   // This is the 'maximum' pulse length count (out of 4096)
#define USMIN 600      // This is the rounded 'minimum' microsecond length based on the minimum pulse of 150
#define USMAX 2400     // This is the rounded 'maximum' microsecond length based on the maximum pulse of 600
#define SERVO_FREQ 50  // Analog servos run at ~50 Hz updates

#define PHOTORESISTOR_COUNT 8

long DELAY_SHORT = 500;
long DELAY_LONG = 1000;
long DELAY_BEETWEEN_CHECKS = 10 * 1000;


#define S2_DOWN 110
#define S2_UP 65
#define S2_REST 110

#define S3_DOWN 30
#define S3_UP 160
#define S3_REST 150

//Standard Servo
#define SHOULDER_MID 90
#define SHOULDER_OFFSET 45

//Servo Number
uint8_t servoL1S1 = 0;
uint8_t servoL1S2 = 1;
uint8_t servoL1S3 = 10;

uint8_t servoL2S1 = 11;
uint8_t servoL2S2 = 12;  //Left pwm
uint8_t servoL2S3 = 2;

uint8_t servoL3S1 = 9;
uint8_t servoL3S2 = 3;
uint8_t servoL3S3 = 8;


uint8_t servoL4S1 = 7;
uint8_t servoL4S2 = 13;
uint8_t servoL4S3 = 14;

uint8_t servoL5S1 = 15;
uint8_t servoL5S2 = 12;  //Right pwm
uint8_t servoL5S3 = 6;

uint8_t servoL6S1 = 5;
uint8_t servoL6S2 = 4;
uint8_t servoL6S3 = 3;

uint8_t servoArray[18] = {
  servoL1S1, servoL1S2, servoL1S3,
  servoL2S1, servoL2S2, servoL2S3,
  servoL3S1, servoL3S2, servoL3S3,
  servoL4S1, servoL4S2, servoL4S3,
  servoL5S1, servoL5S2, servoL5S3,
  servoL6S1, servoL6S2, servoL6S3
};
/*
LEGS:
  3     6
2         5
  1     4
*/


//Photoresistors
// 14, 27, 26, 25, 33, 32, 35, 34
int photoResistor1 = 14;
int photoResistor2 = 27;
int photoResistor3 = 26;
int photoResistor4 = 25;
int photoResistor5 = 33;
int photoResistor6 = 32;
int photoResistor7 = 35;
int photoResistor8 = 34;

int photoresistorArray[] = {
  photoResistor1,
  photoResistor2,
  photoResistor3,
  photoResistor4,
  photoResistor5,
  photoResistor6,
  photoResistor7,
  photoResistor8
};


void setup() {
  Serial.begin(9600);
  Serial.println("Starting with 18 Servos and 8 Light Sensors");

  initPWM(pwmRight);
  initPWM(pwmLeft);

  delayShort();
  allServoResetPos();
}

void loop() {
  for (int i = 0; i < (sizeof(photoresistorArray) / sizeof(photoresistorArray[0])); i++) {
    Serial.println("Photoresistor " + i + ": " + analogRead(photoresistorArray[i]))
  }
  delayShort();
}


void initPWM(Adafruit_PWMServoDriver pwm) {
  pwm.begin();
  pwm.setOscillatorFrequency(27000000);
  pwm.setPWMFreq(SERVO_FREQ);
}

void moveServo(Adafruit_PWMServoDriver pwm, uint8_t servoName, uint8_t degree) {
  pwm.setPWM(servoName, 0, degreeToPulse(degree));
}


void allServoResetPos() {
  for (int i = 0; i < (sizeof(servoArray) / sizeof(servoArray[0])); i++) {
    int angle;
    int leg = (i / 3) + 1;
    int servo = i % 3;
    if (servo == 1) {              //Leg X Servo 1 (Shouler)
      if (leg == 1 || leg == 4) {  // Legs in front
        angle = SHOULDER_MID - SHOULDER_OFFSET;
      }
      if (leg == 2 || leg == 5) {  // Legs in mid
        angle = SHOULDER_MID;
      }
      if (leg == 3 || leg == 6) {  // Legs in back
        angle = SHOULDER_MID + SHOULDER_OFFSET;
      }
    }
    if (servo == 2) {  // Middle Servo
      angle = S2_REST;
    }
    if (servo == 0) {  // Ground Servo
      angle = S3_REST;
    }

    if (leg <= 3) {
      moveServo(pwmLeft, servoArray[i], angle);
    } else {
      moveServo(pwmRight, servoArray[i], angle);
    }
  }
}


uint16_t degreeToPulse(uint8_t degree) {
  return map(degree, 0, 180, SERVOMIN, SERVOMAX);
}
